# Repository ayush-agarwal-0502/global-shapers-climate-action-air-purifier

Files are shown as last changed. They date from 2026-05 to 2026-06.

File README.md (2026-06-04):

# global-shapers-climate-action-air-purifier

Documentation for Air purifier project 

This project is under Global Shapers (WEF Affiliated) , Climate Action team. Currently being worked upon by the Global Shapers New Delhi hub (GSND).

I'm Ayush Agarwal, 2 months volunteer to Global shapers for this project, and I hope that this documentation serves well for the next person that inherits the project after me. Good luck on this project ! I have given very very detailed explanation of the decision making behind the project, the files etc. 

# Mission Statement – 
To make clean and healthy air accessible, and improve public health, through affordable, community-driven technology. 

# Goals – 

**Purification efficacy –** The device must be able to have a reasonable impact on air quality in a reasonable amount of time. 

**Cost –** The device must cost lower than the air purifiers currently commercially available in the market. 

**Assembly –** The device must be simple to assemble, since it will be assembled by Self help groups. 

**Scalable –** The parts used must be widely available in the market. 

## First Principles Thinking – Basic version - 
At its simplest, the air purifier systems must pass air through the filter. 
This filter has to be a HEPA certified filter (HEPA = High-Efficiency Particulate Air), since these are widely regarded to be effective, as opposed to local solutions. 
It must be ensured that the filter is HEPA certified (and not “HEPA like”) to ensure validity of the claim that our air purifier works well. 
So a very basic system would look like a fan passing air through the HEPA filter. 

**Choice of HEPA –**

Cylindrical HEPA filters maximize the surface area for air intake, while sheet based HEPA usually have smaller surface area, hence we decided to proceed with cylindrical HEPA. 

**Choice of Fan –**

The fan must be easily available in the market so that anyone can replicate our work. Therefore, solutions involving BLDC motor (Brushless DC) with custom propellors, support structure etc would not serve us well. 
Therefore we decided to proceed with Gaming fans – these are widely available fans, which are typically used to cool GPUs for gamers. 
Other alternative was to utilize CPU fans, which were far cheaper than Gaming fans, however, their speed and efficiency were much lower than the GPU fans. We need a strong motor to be able to push air through the HEPA filter, cheaper motors just don’t create enough pressure to push air through it. 

## IoT version – 
However, to validate the fact that the device indeed works perfectly, we also need to measure AQI. 
Hence we decided to build this version. 
So, there would be requirement for AQI sensor. 
And, we would need to send the data to be stored, therefore there would be requirement for WiFi module like ESP32 NodeMCU, or ESP8266. 
Simple understanding of the system would be that the AQI sensor would measure the AQI, and would send the data to cloud storage using the WIFI module. 

**Providing intuition for the circuit diagram –** 

Final_schematic_diagram

We are using an Adapter (a device which looks like a phone charger, takes in 220V AC, the voltage commonly available in Indian homes, and converts it to 12V DC, accessible via a cylindrical pin). 
(Future version of it might explore being able to run the system using phone chargers and USB port, however phone chargers typically give out 5V, which was insufficient to run Gaming fans at high speed)
To connect this adapter, we need a 2.1mm Barrel Jack. 
This now serves as 12V Voltage source for our circuit. 
The 12V is fed directly to the motor (the Gaming fan), so that the air purifier works, irrespective of the other parts of circuit working.
We utilize a voltage regulator, to drop the 12V to 5V, since the ESP32 and AQI sensor operate on 5V source (using 12V source will burn the chips, so need to be careful)(Side note – ESP32 takes in 5V, internally steps it down to 3.3V, and then uses it, so some sources may say that ESP32 uses 3.3V)
Also, we would need to cross connect Tx and Rx (Transmitter and Receiver) Pins for ESP32 and AQI sensor. 

# PCB Design – 
The PCB was designed using EagleCAD. 
If the reader has a background in electronics engineering, one can learn PCB design within 3-4 days. 
One can learn PCB design basics at - https://github.com/ayush-agarwal-0502/Electronics-Guidance-Freshers/blob/main/Digisim%20-%20PCB%20Design%20Workshop.pdf

There is a schematic file (containing the circuit diagram), a board file (containing the routing), and Gerber File (what we typically send to manufacturers so that the PCB gets printed). 
The PCB can be visualized at Online Gerber Viewer - https://www.pcbway.com/project/OnlineGerberViewer.html

I have uploaded the PCB files in this repository. 
I have used Female Pinheads – so that the team assembling it can simply take our PCB, buy ESP, AQI sensor, motor etc , and then its simple plug and play. We cannot expect our end customers to be experts in soldering, hence the need for PCB. Doing this ensures even non electronics people can assemble the chip. 





# Quick start on PCB design – 

* Install EagleCAD. 
* Make the circuit diagram on the schematic file (use “Add Parts” to add parts, use “Net” to add the wires, and you may need to manually add library for ESP32 so that the pins correspond perfectly to the ESP. Also, ports for devices can be added using “Pinhead” part, since these would have to be connected to other chips. 
* Make the board file (top bar – left mid side). Place the parts on the chip. Take care that the ports etc should be on the edges, just like in real chip, imagine as if the other chips were going to be plugged into it, and so leave the gaps accordingly. 
* Add holes in the corners, so that later when the PCB comes we have holes to screw it in. 
* Use autorouter to route the traces (traces are copper lines on PCB which carry the current). Change the trace thickness to 20 mils or more before running the autorouter to avoid heating (mils are a unit of measurement for PCBs).
* Use autorouter to route the traces (traces are copper lines on PCB which carry the current). Change the trace thickness to 20 mils or more before running the autorouter to avoid heating (mils are a unit of measurement for PCBs).
Type POLYGON GND in the command line (top side white textbox), and draw rectangle around the chip, on both top and bottom layer, and declare signal name as GND. Once done, type RATSNEST. This will cover the remaining area with copper, to provide cooling to the chip. 
(Side note – you can use “RIPUP @;” command to remove the ratsnest.) 
* Go to tPlace (layer 21 or something) and use Text tool to add white coloured text to the chip, make sure to label all the pins nicely, as it will help in the assembly. 
* Run ERC and DRC in the command line, these are Electrical Rule Checks and Design Rule checks. If DRC fails, you may be required to manually add traces, and remove the autorouter ones. 
* Go to file, CAM, and make sure of these options – Export as ZIP, convert all Text to CSV etc , and then hit export, and it will generate the Gerber File. 
* Go to the “Assembly” folder in the generated excel file, add remarks, and add instructions to solder Female headers whereever required. 
* Also, right side, there is option to export picture of the PCB, use that instead of taking screenshot. 

# Manufacturing and Supply Chain design - 

Manufacturing is a different beast in itself, I'll keep adding insights here - 

Firstly, we have to look for PCB Manufacturers. 
We dont look for just PCB manufacturers, rather, the correct industry term is PCB turnkey manufacturers, or PCBA (PCB assembly). 
Since we as a social impact group do not have the liberty to hire someone full time to solder components, it is essential that the female connectors, vooltage regulator, barrel jack etc come pre soldered onto the PCB. 

PCBWay is popular, however it is China based, thus additional costs in taxes due to border crossing, therefore I did not go for it. Moreover, "Made in India" would be better. 

I found 2 nice manufactureres - Lion Circuits and PCBPower. Finally we went with LionCircuits as the quote was far lower. 

The manufacturers would require the Gerber Files, and the other files that EagleCAD already produces. 
Additionally, MPN (Manufacturer Part Number) is required for all the components that need to be soldered upon the PCB, these can be verified properly from Mouser Website. 

In manufacturing, we have a concept of MOQ (Minimum Order Quantity). Most manufactureres wont manufacture below 5 pcbs at a time. Also, producing lesser pcbs has high cost per pcb, whereas when we produce at large scale, the cost per pcb decreases significantly. 

Additionally, we have to source the parts (Gaming Fan, NodeMCU ESP32, AQI sensor etc) so that we can order easily when we reach production. 



LionCircuits for 5 PCBs - 





[Note - the 19 pin array needs to be manually negotiated, while the website only allows me specific MPN, so I had to put an expensive brand which is driving up the cost, however practically the manufacturer can easily find cheaper alternatives locally (whose MPN we cannot find) ]

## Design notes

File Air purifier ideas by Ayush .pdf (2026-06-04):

# Air purifier ideas

## By Ayush Agarwal

## https://www.linkedin.com/in/ayush-agarwal-261041215/

## How to make it = First Principles Thinking

Lets break it into parts, and then solve.

ELIMINATABLE PARTS -

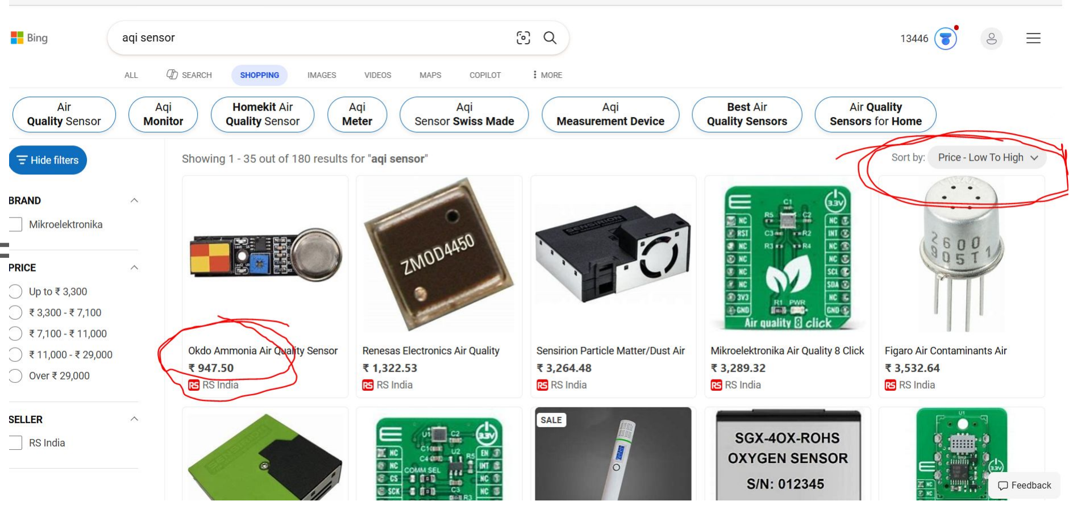
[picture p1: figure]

Parts that are “good to have” but not “must have” =

- AQI sensors (these are very expensive),
- Speed control for Fan circuit.

If you remove these both, you wont even need PCB, circuit will be simple.

PCB manufacturing + shipping is costly, and soldering the parts is labour intensive.

[https://www.linkedin.com/in/ayush-agarwal-261041215/ ]

## Dropping Chassis cost to near 0 !

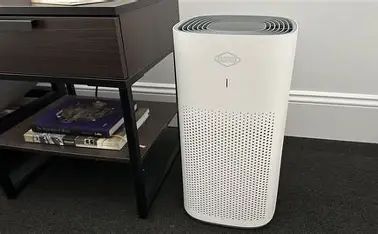
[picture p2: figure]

Plastic Box -

- Costly.
- Not Sustainable
- Difficult to transport

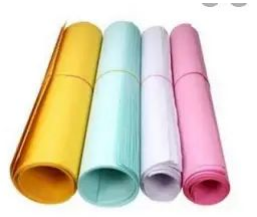
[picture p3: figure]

Chart paper rolls -

- Ultra Cheap
- Sustainable
- Can be bulk transported and assembled in 1000s

## But how will chart paper even work -

Using origami skills, I believe it is possible.

[Proceeds to show demo with rough paper]

Note - Worst case, if it dosent work, we can make rectangular pipe using Cardboard.

## HEPA ?

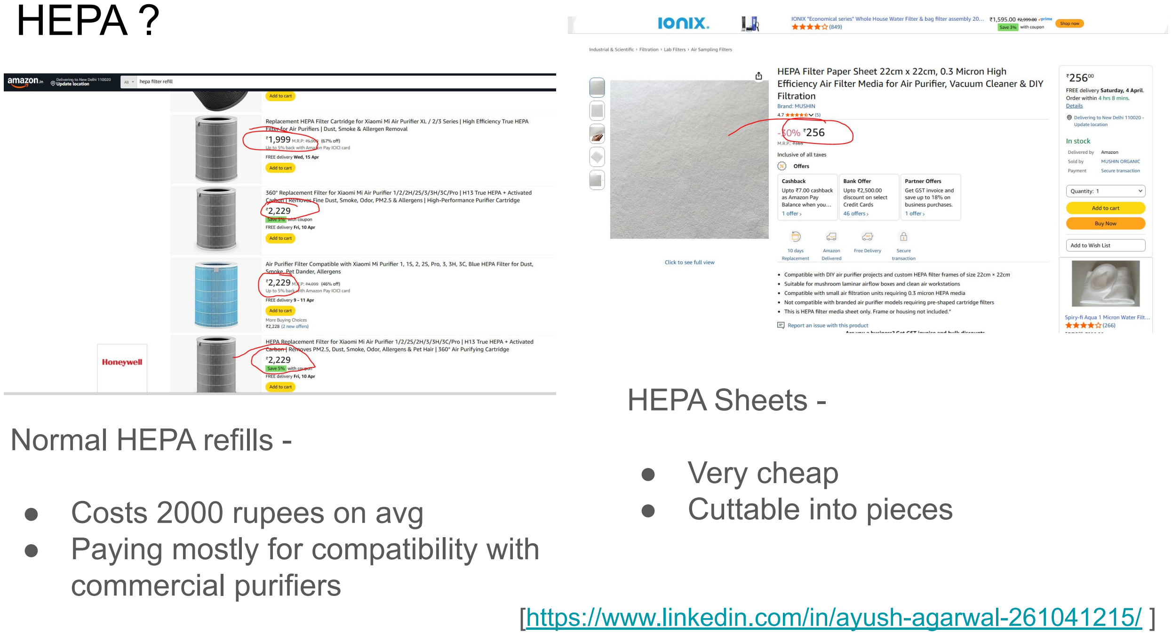
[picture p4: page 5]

HEPA Sheets -

- Very cheap
- Cuttable into pieces

Normal HEPA refills -

- Costs 2000 rupees on avg
- Paying mostly for compatibility with commercial purifiers

## Fans ?

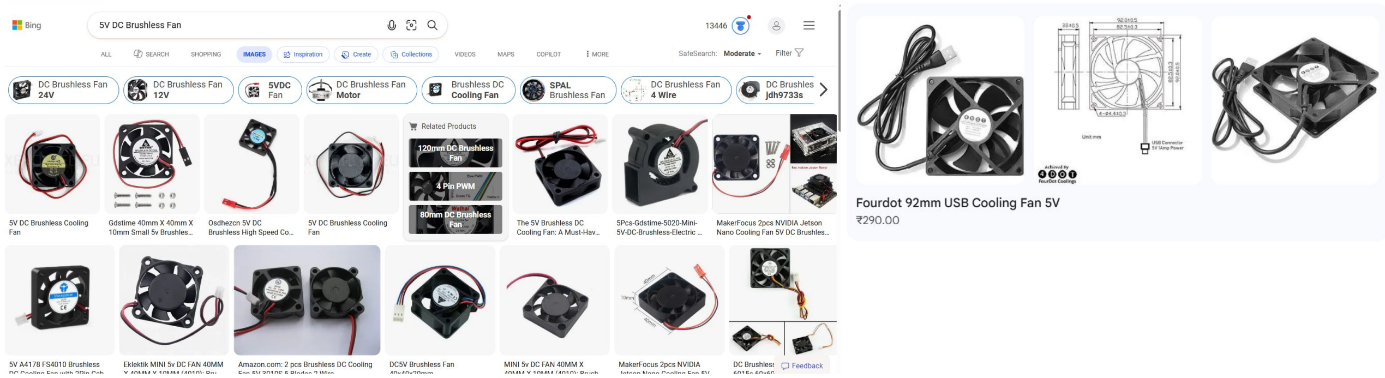
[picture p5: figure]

Remember these fans inside old CPUs?

We can use them, no need to manually attach propellor to motors etc

Drops manufacturing cost, plus no fire risk now

## Wiring ? Killing the need for adapter

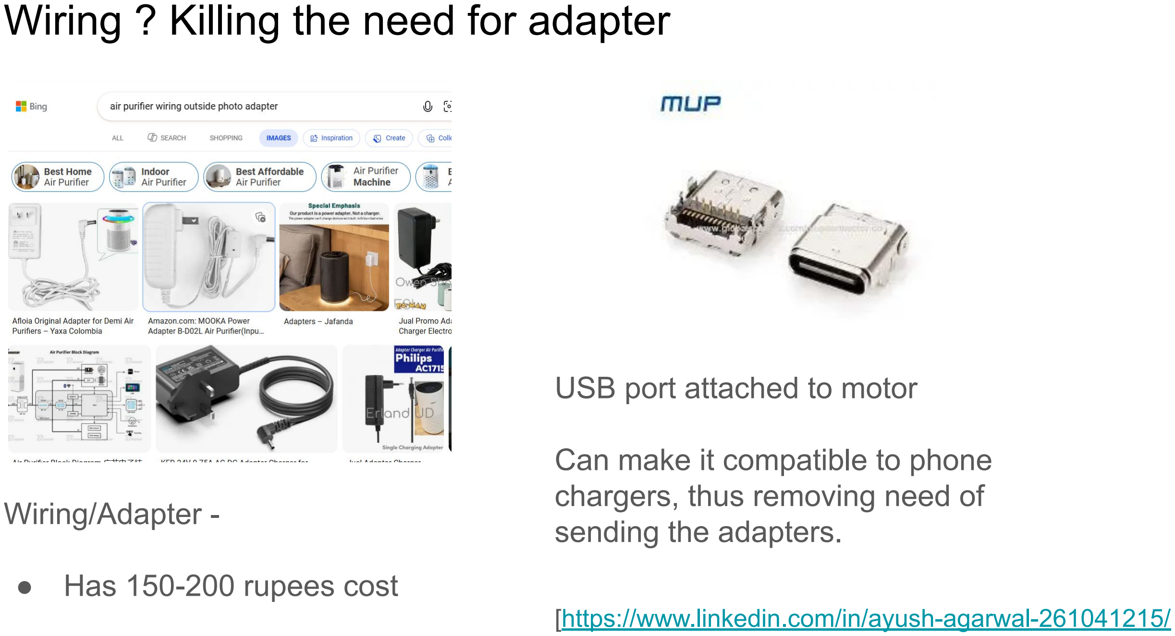
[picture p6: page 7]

Wiring/Adapter -

- Has 150-200 rupees cost

USB port attached to motor

Can make it compatible to phone chargers, thus removing need of sending the adapters.

## Its a billboard

Since we are using chart paper.

We can sell the advertising spots on the chassis to companies, further dropping price by 20-30 rupees.

Plus CSR funding

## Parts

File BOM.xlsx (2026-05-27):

Sr No | Designator | MPN | Quantity | Description
1 | U$1 | PJ-102A | 1 | DC Barrel Jack
2 | U2 | R-78E5.0-1.0 | 1 | Recom 5V 1A Regulator
3 | AQI_SENSOR | 61300511821 | 1 | 5-Pin Female Header (for the sensor)
4 | MOTOR | 61300411121 | 1 | 4-Pin Male Header (for the fan)
5 | U1 | SSW-119-01-T-S | 2 | 19-Pin Female Headers (for the ESP32)

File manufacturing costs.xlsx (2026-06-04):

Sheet: parts_procurement_sourcing
 |  | Justification
Air sensor - | Zph02 Dust Sensor,Pm2.5 Sensor Module For Household Air Purifiers,Laser Dust Sensor - Buy Zph02 Dust Sensor Pm2.5 Sensor Module For Household Air Purifiers Laser Dust Sensor Product on Alibaba.com (https://www.alibaba.com/product-detail/ZPH02-Dust-Sensor-PM2-5-Sensor_1601521252134.html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) | [Was used by Arjun, hence considered reliable]
ESP32 NodeMCU | Buy ESP WROOM 32 MCU Module Online at Best Price In India | Robu.in | Robu.in (https://robu.in/product/esp-wroom-32-esp32-wifi-bt-ble-mcu-module/) | [Robu also does B2B partnerships, and has been a reliable supplier for robotics club in my college, hence I trust that it will be able to supply when we reach bulk production stage]
 | ESP32 NodeMCU is the most widely availaible chip, can buy any of it as long as it has 19 pins each side, and the pin config matches the one Ive drawn on PCB
Gaming Fan | [Will be added by Aditi, has been sourced by her already ]

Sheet: PCBA_manufacturing_costs
 | Lion Circuits | Lion Circuits (https://order.lioncircuits.com/projectdetails/219942)
OQ (Order Quantity) | Fabrication | Assembly | Procurement | GST |  | Price per board |  | Fab/Chip | Assembly/Chip
5 | 1079 | 1500 | 2578.26 | 604 | 5761.26 | 1152.252 |  | 215 | 1500
25 | 3191 | 3434 | 11092 | 3189 | 20906 | 836.24 |  | 127
50 | 5832 | 5918 | 21243 | 5939 | 38932 | 778.64
100 | 9636 | 9705 | 39751 | 10637 | 69729 | 697.29
 | Result of all analysis = found Lion Circuits to be the most economical and reliable for our needs :)
 | pcb power - | site was forcing me to make pick place file, so I left it
 | pcb power - | Had received call from the salesperson, did discussion on gerber file, mpn etc, finally got quote 2000 per pcb which was very high :(
 | Robu - | there was a preview box, which was not showing anything, idk y , and also im not sure if they do full assembly or not, didn’t see any option
 | PCBWay - | Chinese company we have to avoid to avoid paying border tax |  |  |  |  | 25-30 dollars only for shipping |  |  | that’s 3k bucks extra, lion pe delivery free thi, plus this is excluding customs tax
 | Mefron - | Did not have anything on their website to check price, straight up a form to collect my data like phone number, old sales style website
 | PCB Scientist - | Its in Gugraon, but even on their website they have only given a phone number and mail, so I don’t think they are much in business

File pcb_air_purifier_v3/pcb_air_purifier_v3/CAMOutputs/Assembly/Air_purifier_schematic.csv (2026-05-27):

Part | Value | Device | Package | Description | AVAILABILITY | CHECK_PRICES | DESCRIPTION | MF | MP | PACKAGE | PRICE | PROD_ID | SNAPEDA_LINK | Remarks
AQI_SENSOR |  | CONN_05 | 1X05 | Multi connection point. Often used as Generic Header-pin footprint for 0.1 inch spaced/style header connections |  |  |  |  |  |  |  |  |  | Solder 1x05 Female Header on TOP side. Do not solder sensor directly.
MOTOR |  | CONN_04PTH | 1X04 | Multi connection point. Often used as Generic Header-pin footprint for 0.1 inch spaced/style header connections |  |  |  |  |  |  |  | CONN-09696 |  | Solder 1x04 Male Header on TOP side.
U$1 | 2.1MMJACKTHM | 2.1MMJACKTHM | PJ-102A | 2.1mm x 5.5mm THM DC jack with internal switch. Digikey part #PJ-102A 4UCON part #05537 |  |  |  |  |  |  |  |  |  | Solder DC Jack on TOP side. Ensure the 2.1mm barrel entry faces the edge of the board as per the silkscreen
U1 | ESP32_NODEMCU | ESP32_NODEMCU | MODULE_ESP32_NODEMCU | Check availability | Not in stock | https://www.snapeda.com/parts/ESP32%20NODEMCU/AZ+Displays/view-part/?ref=eda | low power system-on-chip (SoC) microcontrollers with integrated Wi-Fi and dual-mode Bluetooth. | AZ Delivery | ESP32 NODEMCU | Package NodeMCU is an open source loT platform. ESP32 is a series of low cost | None |  | https://www.snapeda.com/parts/ESP32%20NODEMCU/AZ+Displays/view-part/?ref=snap | Solder two 1x19 Female Headers on TOP side.
U2 | R-78E5.0-1.0 | R-78E5.0-1.0 | DC-DC_CONVERTER_78XX | Recom Power 5V 1A DC/DC Converter |  |  |  |  |  |  |  | COM-13655 |  | Solder Voltage Regulator (Vin=12V, Vout=5V) on TOP side. Match the component pins (Input, GND, Output) strictly with the board's silkscreen markings

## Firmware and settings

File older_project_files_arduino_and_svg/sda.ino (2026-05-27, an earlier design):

/* * ESP32-C3 Air Purifier System
 * * FEATURES:
 * 1. VISUAL: Smooth RGB Gradient (Green -> Yellow -> Red -> Purple)
 * 2. FAN: Custom Speed Ranges (Silent -> Turbo)
 * 3. CLOUD: ThingSpeak Logging
 */

#include <WiFiManager.h> 
#include <HTTPClient.h>

// --- HARDWARE CONFIGURATION ---
#define RXD2 20            
#define TXD2 21            
#define FAN_PIN 5          

// --- THINGSPEAK SETTINGS ---
const char* server = "http://api.thingspeak.com/update";
String apiKey = "1KGLC25WWVX0P5PB"; 
const unsigned long uploadInterval = 30000; 

// --- GLOBAL VARIABLES ---
float currentLPO = 0.0;    
float currentMass = 0.0;   
int currentAQI = 0;        
int currentVOC = 0;        
unsigned long lastUploadTime = 0;

void setup() {
  Serial.begin(115200);
  
  // 1. Setup Sensor
  Serial1.begin(9600, SERIAL_8N1, RXD2, TXD2);

  // 2. Setup Fan
  ledcAttach(FAN_PIN, 25000, 8); 
  ledcWrite(FAN_PIN, 255); // Startup "Whoosh"
  delay(500);
  ledcWrite(FAN_PIN, 0);

  // 3. Initialize RGB (Blue = Setup)
  #ifdef RGB_BUILTIN
    rgbLedWrite(RGB_BUILTIN, 0, 0, 50); 
  #endif

  // 4. WiFi
  WiFiManager wm;
  if (!wm.autoConnect("GlobalShapers_Purifier")) {
    ESP.restart(); 
  }
  
  Serial.println("WiFi Connected!");
  #ifdef RGB_BUILTIN
    rgbLedWrite(RGB_BUILTIN, 0, 50, 0); // Green Flash
    delay(1000);
  #endif
}

// --- HELPER: Set RGB Color ---
void setRawRGB(int r, int g, int b) {
  #ifdef RGB_BUILTIN
    // Divide by 5 for brightness control
    rgbLedWrite(RGB_BUILTIN, r/5, g/5, b/5); 
  #endif
}

// --- LOGIC 1: SMOOTH COLOR TRANSITION ---
void updateSmoothColor(float mass) {
  int r = 0, g = 0, b = 0;

  // We interpolate (fade) between colors based on Mass value
  
  // Phase 1: 0 to 50 (Green -> Yellow)
  if (mass <= 50.0) {
    // Green is (0, 255, 0), Yellow is (255, 255, 0)
    // Red increases from 0 to 255. Green stays max.
    r = map(mass, 0, 50, 0, 255);
    g = 255;
    b = 0;
  }
  // Phase 2: 50 to 100 (Yellow -> Red)
  else if (mass <= 100.0) {
    // Yellow is (255, 255, 0), Red is (255, 0, 0)
    // Green decreases from 255 to 0. Red stays max.
    r = 255;
    g = map(mass, 50, 100, 255, 0);
    b = 0;
  }
  // Phase 3: 100 to 200 (Red -> Purple)
  else if (mass <= 200.0) {
    // Red is (255, 0, 0), Purple is (128, 0, 128)
    // Red decreases slightly, Blue increases significantly
    r = map(mass, 100, 200, 255, 128);
    g = 0;
    b = map(mass, 100, 200, 0, 128);
  }
  // Phase 4: 200 to 300+ (Purple -> Maroon)
  else {
    // Purple is (128, 0, 128), Maroon is (128, 0, 0)
    // Blue fades out to 0
    float cappedMass = (mass > 300.0) ? 300.0 : mass;
    r = 128;
    g = 0;
    b = map(cappedMass, 200, 300, 128, 0);
  }

  setRawRGB(r, g, b);
}

// --- LOGIC 2: FAN SPEED CONTROL ---
void updateFanSpeed(float mass) {
  int fanSpeed = 0;
  
  if (mass <= 10.0) {
    fanSpeed = 12;   // Silent
  } 
  else if (mass <= 30.0) {
    fanSpeed = 80;   // Low
  }
  else if (mass <= 60.0) {
    fanSpeed = 190;  // High
  } 
  else {
    fanSpeed = 255;  // Turbo (Above 60)
  }
  ledcWrite(FAN_PIN, fanSpeed);
}

// --- LOGIC 3: EPA AQI CALC (For Cloud) ---
int calcEPA_AQI(float pm25) {
  float c = pm25;
  if (c <= 9.0)    return map(c*10, 0, 90, 0, 50);
  if (c <= 35.4)   return map(c*10, 91, 354, 51, 100);
  if (c <= 55.4)   return map(c*10, 355, 554, 101, 150);
  if (c <= 125.4)  return map(c*10, 555, 1254, 151, 200);
  if (c <= 225.4)  return map(c*10, 1255, 2254, 201, 300);
  if (c <= 325.4)  return map(c*10, 2255, 3254, 301, 400);
  if (c <= 500.4)  return map(c*10, 3255, 5004, 401, 500);
  return 500; 
}

void uploadData() {
  if (WiFi.status() == WL_CONNECTED) {
    HTTPClient http;
    String url = String(server) + "?api_key=" + apiKey + 
                 "&field1=" + String(currentMass) + 
                 "&field2=" + String(currentAQI) + 
                 "&field3=" + String(currentVOC);
    
    http.begin(url);
    int httpCode = http.GET();
    if (httpCode > 0) Serial.println("ThingSpeak Upload Success.");
    http.end();
  }
}

void loop() {
  if (Serial1.available() >= 9) {
    if (Serial1.read() == 0xFF) {
      byte buf[9];
      buf[0] = 0xFF;
      for (int i = 1; i < 9; i++) buf[i] = Serial1.read();

      byte checksum = 0;
      for (int i = 1; i < 8; i++) checksum += buf[i];
      checksum = (~checksum) + 1;

      if (checksum == buf[8]) {
        currentLPO = buf[3] + (buf[4] / 100.0);
        currentMass = currentLPO * 10.0;
        currentAQI = calcEPA_AQI(currentMass);
        currentVOC = buf[7];

        // 1. Update Smooth LED
        updateSmoothColor(currentMass);

        // 2. Update Fan Speed
        updateFanSpeed(currentMass);

        // Debug
        Serial.printf("Mass: %.2f | AQI: %d | VOC: %d\n", currentMass, currentAQI, currentVOC);
      }
    }
  }

  if (millis() - lastUploadTime > uploadInterval) {
    uploadData();
    lastUploadTime = millis();
  }
}

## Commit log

2026-05-06 Enhance README with project documentation and details
    Added detailed documentation for the air purifier project, including mission statement, goals, design choices, and PCB design instructions.
2026-05-27 Added pcb files (gerber, drill, assembly)), BOM, arduino inherited files, inherited svg (which seems incorrect tbh)
    [Air_purifier_schematic.csv, BOM.xlsx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]
2026-06-04 Revise manufacturing and supply chain design section
    Updated sections on manufacturing and supply chain design, including details on PCB manufacturers and sourcing components.
